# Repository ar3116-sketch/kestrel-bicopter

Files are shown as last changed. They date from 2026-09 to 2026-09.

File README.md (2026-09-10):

# Kestrel Mini R4

A matte-black, Black Hawk inspired **bicopter**, modeled in FreeCAD with electronics and wiring. Two lift motors and two independent tilt servos provide the control inputs. There is no tail rotor.

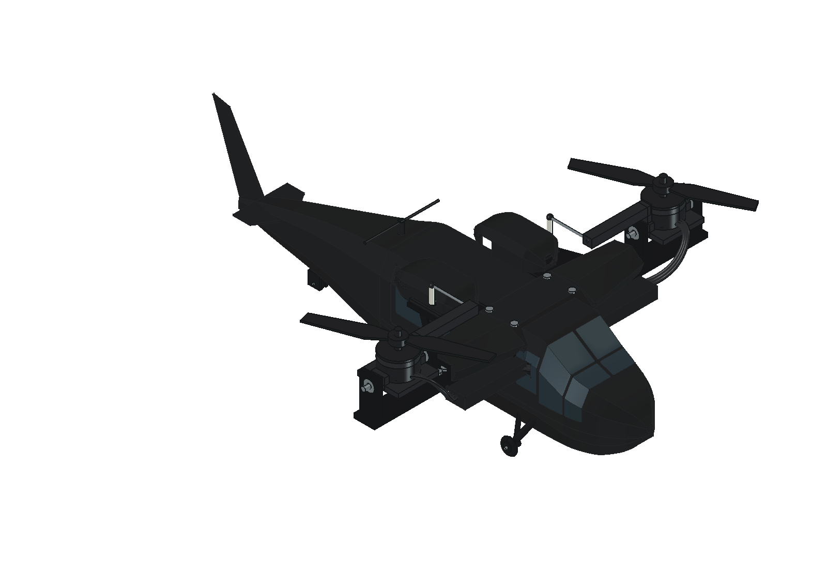
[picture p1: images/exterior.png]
Kestrel exterior


**Fit prototype, not flight-qualified.** Estimated mass is **665 g**, or **731 g with 10% growth**. Calculations support takeoff in principle. Actual thrust, servo tracking, printed strength, assembly retention and flight-controller integration still need physical verification.

## Start here

- [PDF build and engineering guide](output/pdf/Kestrel_Mini_R4_Build_Guide.pdf)
- [Parts list: buy, print and bench equipment](docs/PARTS_LIST.md)
- [FreeCAD assembly](cad/Kestrel_Mini_R4.FCStd) and [STEP](cad/Kestrel_Mini_R4.step)
- [40 installed STL pieces](stl/) and [2 optional guards](stl/optional_guards/)
- [Wiring overview](engineering/wiring_overview.svg) and [42-route wire schedule](engineering/WIRE_SCHEDULE.md)
- [Engineering review](engineering/ENGINEERING_REVIEW.md), [flight audit](engineering/INDEPENDENT_FLIGHT_AUDIT.md), and [tail assessment](engineering/TAIL_ASSESSMENT.md)
- [Assembly and qualification plan](docs/BUILD_AND_TEST.md)
- [Reproduction instructions](REPRODUCE.md)

Open the FCStd in FreeCAD. Run `OPEN_KESTREL.FCMacro` for shell visibility and independent tilt inspection. The +/-25 degree sliders show geometric articulation; they are not validated operating limits. The native file is a grouped installation model, with provisional purchased-part envelopes and a Python geometry generator, rather than a fully constrained assembly/feature history.

## What the calculations say

| Case | Estimated mass | Vertical thrust/weight at 12 V | At 16 V |
|---|---:|---:|---:|
| Baseline | 665 g | 1.82 | 2.29 |
| 10% mass growth | 731 g | 1.65 | 2.09 |

These use the published original EMAX RS2205 2300KV / HQ5045BN two-blade table with an **assumed 15% installation loss**. The assumption is not a measured guarantee. At the growth mass and low voltage, the design misses its preferred 1.8 vertical margin. Bank, tilt, simultaneous commands and gusts consume reserve. Fresh-pack 16.8 V is outside the available thrust table.

The tail prints weigh **30.9 g**, already counted in the baseline. The calculated CG lies 0.82 mm aft of the rotor pivot plane. The tail is not inherently incompatible with bicopter control, but crosswind and its added rotational inertia matter; see the dedicated assessment. No wind envelope is approved.

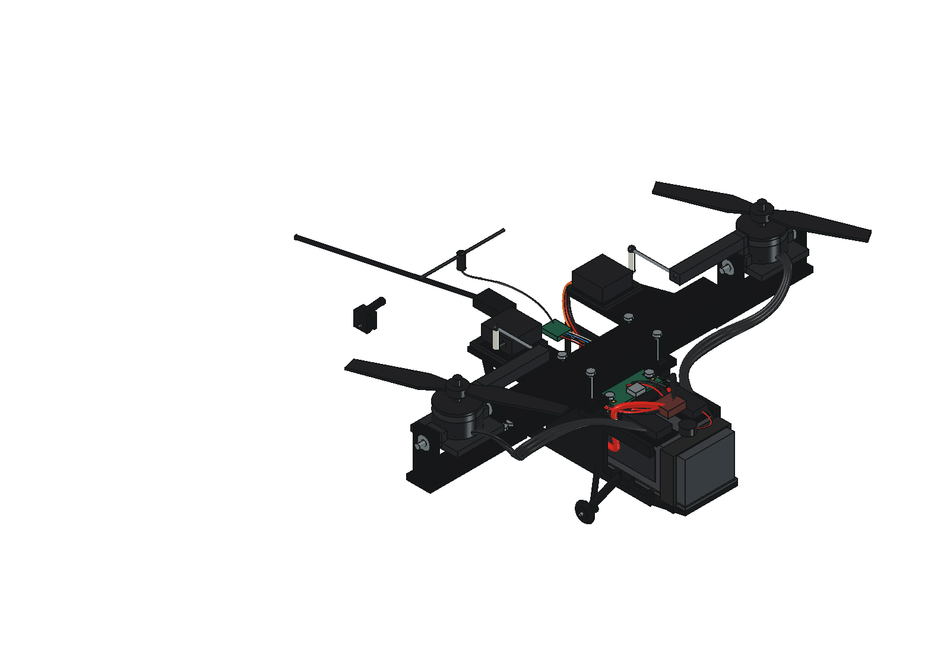
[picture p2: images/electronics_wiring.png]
Installed electronics and wiring


## Evidence and open work

The R4 checks report 167 valid physical shapes, 42 closed printable meshes, 22 sampled rotor poses and 42 neutral wire routes. Minimum prop-to-fixed clearance in the sampled poses is 9.906 mm. The wiring check uses finite mesh sampling, not continuous flexible-harness simulation. No physical tests, CFD, validated full-flight simulation or flight qualification have been completed.

Battery SKU, final hardware interfaces, tail splice and retention, motor/ESC/servo thermal performance and exact firmware configuration remain open. Do not treat a successful CAD or mathematical check as proof of an airworthy build.

The manufacturer material in `source/` is retained for engineering traceability; see [NOTICE](NOTICE.md). This project is an independent hobby design and is not affiliated with Sikorsky, Lockheed Martin or the hardware manufacturers.

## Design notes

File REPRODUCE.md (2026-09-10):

# Reproduce the prototype checks

The native FreeCAD file is a grouped installation model with named parts and wires. The generator creates Part/PartDesign features from dimensions; the DesignBasis spreadsheet documents parameters and does not drive a live constrained feature history. Purchased parts are installation envelopes; detailed received-hardware interfaces remain provisional.

From this folder, run `python3 scripts/analyze.py`, then `python3 scripts/independent_audit.py` for the mass, thrust, control and structural screens. These use the saved inventory and source tables. Run `python3 scripts/write_report.py` and `python3 scripts/wiring_diagram.py` to regenerate the reports and wiring overview.

Run `scripts/build_freecad.py` inside FreeCAD to rebuild geometry. It closes and recreates the document named Kestrel_Mini_R4, so preserve any manual edits under a different name first. Keep `scripts/profile_surfaces.py` beside it. The original Samson and previous Kestrel revisions are separate files. Shell skin uses a section-coordinate inset, not a guaranteed exact surface-normal thickness.

For isolated read-only geometry checks, use FreeCADCmd with `scripts/check_fixed_clearances.py` and `scripts/check_wire_samples.py`. The latter uses NumPy and records its finite sampling resolution, constructive passage exclusions, canonical source hash and native-file hash. It does not prove continuous motion clearance or flexible wire behavior. The fixed check examines selected component pairs and 22 rotor poses; its method is separate from the wire sampling check.

With the native document open in FreeCAD, `scripts/refresh_exports.py` refreshes inventory, closed-mesh/size checks, STL files, STEP and the saved document. Run the analytical and geometry checks again after any geometry or hardware change. Run the wire check after the final native-file save so its recorded hash matches the delivered file. `scripts/package_release.py` validates the evidence and packages selected artifacts; its name refers to an archive release, not flight qualification.

`OPEN_KESTREL.FCMacro` provides shell visibility and independent ±25° inspection sliders. It hides neutral phase-wire paths while tilted, and returns the pods to neutral when closed. The ±25° geometric display is not a validated flight limit.

## Repository documentation and PDF

After analytical changes, run `python3 scripts/tail_audit.py` and `python3 scripts/build_parts_list.py`. The first performs a limited tail mass/inertia and crosswind sensitivity screen; it does not validate an aerodynamic coefficient or wind envelope.

Install `requirements-docs.txt` into a Python environment and run `python3 scripts/build_pdf.py` to recreate `output/pdf/Kestrel_Mini_R4_Build_Guide.pdf`. The PDF builder needs ReportLab/Pillow; the independent flight audit also requires NumPy. FreeCAD and its OCCT modules are required separately for CAD operations. Render the PDF with Poppler and inspect all pages after any content change; PDF byte hashes vary with build timestamps.

Run `python3 scripts/package_release.py` after the saved CAD and reports agree. It checks existing geometry evidence, refreshes `MANIFEST_SHA256.json` and creates `outputs/Kestrel_Mini_R4_Repository.zip`, including the PDF, parts list and tail assessment. It does not repeat all underlying CAD computations. Historical `outputs/` and temporary PDF renderings are ignored by Git.

Run `python3 scripts/verify_repository.py` for a read-only manifest, native-file, parts/mass and local-link consistency check. Refresh the manifest after intentional modifications. Repository validation does not change `flight_release=false`.

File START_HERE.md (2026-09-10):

# Kestrel Mini R4

Black Hawk inspired bicopter in matte black, built in FreeCAD. Two propulsion motors, two tilt servos; optional guards are hidden in the baseline view.

Revised exterior

**665 g estimated / 731 g with 10% growth. Preliminary design; not flight released.**

Open [the FreeCAD assembly](cad/Kestrel_Mini_R4.FCStd) or run `OPEN_KESTREL.FCMacro` inside FreeCAD for the shell switch and tilt sliders. [STEP assembly](cad/Kestrel_Mini_R4.step) is also included.

Read [the independent flight audit](engineering/INDEPENDENT_FLIGHT_AUDIT.md), [the engineering review](engineering/ENGINEERING_REVIEW.md) and [wire schedule](engineering/WIRE_SCHEDULE.md) before printing or buying. `stl/` contains 40 installed fit-prototype parts sized for the Centauri Carbon. `stl/optional_guards/` contains the two optional guards, totaling 25.4 g. Exact hardware interfaces and physical acceptance tests remain open.

Electronics and wiring

Calculations predict enough lift near the nominal mass, with roughly 3–4 minutes of hover on a 4S1300 pack. The screenshot's four-cell 21700 pack would put this design around 799 g before contingency, so it is not the baseline.

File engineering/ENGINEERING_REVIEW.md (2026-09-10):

# Kestrel Mini R4 — engineering prototype

Designed in FreeCAD, 9 September 2026. Revision reflects the requested matte-black Black Hawk inspired silhouette: short rounded nose, sloping windshield, rectangular cabin windows, hollow roof fairings, low tail boom, swept fin and wheel gear. Original geometry inspired by the user's larger Samson model; no original CAD was overwritten. The two screenshot parts lists are references, not commands. No parts have been bought.

**Digital design and preliminary feasibility only. The aircraft has not been built, weighed, thrust-tested, structurally proof-tested, or flown. CAD cannot certify that it will fly.** This package is suitable for design review and fit prototypes; it is not a released flight kit.

## Main result

The calculated nominal build is **665 g**, including a **77 g installation allowance**. The budget with 10% growth is **731 g**, leaving **69 g** below the user's 800 g ceiling. Printed material is **251 g**, evaluated at full CAD solid volume and a conservative assumed 1.24 g/cm³. This is not a slicer prediction or measured print mass.

There are **167 modeled objects including two optional guards**, **40 installed printable pieces**, and **42 individually modeled wire routes**. Rotor center spacing is 234 mm and prop diameter is 127 mm, giving 361 mm overall rotor span without guards. The swept fin gives approximately 386 mm overall length. Optional guards have 142.2 mm OD and 376.2 mm overall span. Body dimensions are not a uniform scale of the old design. The old package recorded 2699.9 g before contingency; this design is about 75% lighter on its own mass basis.

At nominal mass, the reference calculation with an assumed installation factor gives vertical thrust/weight of 1.82 at 12 V and 2.29 at 16 V, with installed thrust assumed to be 85% of the manufacturer stand result. Expected static hover duration is roughly **3–4 minutes** using 80% of nominal pack energy. Airflow obstruction, battery aging, wind, maneuvering and actual material mass can worsen this.

**The model predicts enough static lift at nominal weight. Maneuvering and stable controlled flight are not yet established.** The independent audit in `INDEPENDENT_FLIGHT_AUDIT.md` corrects the earlier servo-gyro omission and shows the sensitivity to weight and installed thrust. The 85% factor is an assumption, not a measured conservative bound. Keep the initial build near the nominal mass. At the 800 g ceiling, low-voltage tilt reserve is substantially weaker. The baseline omits the guards. Fitting both adds 25.4 g, taking nominal mass to 690 g. No positive thrust gain is credited to them. Current screens below are analytical limits; hardware has not been configured to enforce them.

## What to open

- `cad/Kestrel_Mini_R4.FCStd`: native FreeCAD assembly, individual objects, mass properties, named nets and grouped electronics.
- `cad/Kestrel_Mini_R4.step`: neutral assembly, commercial components represented by simplified installation envelopes.
- `OPEN_KESTREL.FCMacro`: open the model with independent tilt sliders and a shell on/off switch. Wiring depicts neutral installation; flexing wires are hidden when articulating.
- `stl/`: installed fit-prototype parts, moved to positive print coordinates; optional guards are in their own subfolder. Propellers are deliberately excluded.
- `engineering/calculations.json`, `inventory.json`, `final_clearance_report.json`, `wiring_routes.json`: reproducible detailed evidence.
- `scripts/build_freecad.py`: dimension-driven generator; edit the geometry parameters in this source and rebuild inside FreeCAD. The DesignBasis spreadsheet is documentation, not live constraint linkage.

## Two motors and maneuvering

Yes: two independently controlled, counter-rotating propulsion motors plus two independent tilt servos provide the four primary control inputs. Collective thrust controls climb/descent, differential thrust controls roll, common fore/aft rotor tilt supplies pitch/forward-backward control, and differential fore/aft tilt supplies yaw. Sideways motion uses banking; this is not six independently actuated axes. A supported flight controller mixes and stabilizes these coupled motions. A tail rotor is not required in this arrangement. The tail fin is a body feature, not a substitute for active stabilization. Betaflight lists its BI airframe with two motors and two servos [7].

## Mass and balance

| Allocation | Grams |
|---|---:|
| Installed printed airframe, shell, cradles, gear and mounts | 250.9 |
| Purchased components already allocated in CAD | 337.0 |
| Harness and secondary connectors | 36 |
| Additional screws, nuts, spacers and retention hardware | 25 |
| Straps, foam, ties and insulation | 8 |
| Adhesive and light finish | 8 |
| Nominal | 664.9 |
| With 10% growth | 731.4 |

The purchased total includes two motors (60 g), two props (6 g), two ESCs (16 g provisional), two Blue Bird digital servos (24 g planning), FC (10 g), receiver including antenna (2.2 g), UBEC (21 g), battery with stock leads (170 g allowance), main XT60 (4 g), input capacitor (3 g), buzzer (2 g), four MR104 bearings (5.2 g assumed), metal trunnions (8 g assumed), two horns (1.6 g) and links (4 g). The supplementary hardware and harness allowances intentionally remain even where simplified zero-mass CAD markers exist. Some stock wire mass is also covered conservatively by the harness floor. Nothing is reclaimed as fictitious margin.

Coordinate convention: +X nose/forward, +Y left, +Z up. Origin is midway between rotor axes in plan at z=0; actual transverse pivots are at z=35 mm. Estimated all-up CG = **(-0.82, -0.03, 4.44) mm**. Nominal pitch moment arm from CG to pivot is **30.6 mm**. Sliding the battery is the balancing adjustment. Target actual CG within ±2 mm in X/Y of the pivot centerline; do not assume a low battery makes a bicopter passively stable. The estimated X error implies about 1.5° geometric trim, with final correction based on measured CG. The nominal calculation is inside the ±2 mm target; measure and trim the assembled aircraft. The layout places the battery center at x=39 mm and relocates the XT60, balance plug and capacitor aft of the pack. Main leads run in side channels; the cosmetic roof covers are hollow.

Bounding-box approximations to the principal inertias are 0.00231, 0.00222, 0.00371 kg·m². These are only model inputs; measure inertia or retune to the built aircraft. A ±50% control-effectiveness range was screened in the simplified simulation.

## Propulsion and energy calculation

Reference is **genuine EMAX RS2205 2300KV with HQ5045BN two-blade props**, with a matched CW/CCW pair. RS2205-S, generic RS2205 clones, different KV, and similarly named triblades are not equivalent evidence. The original EMAX table is retained in `source/motor_2.jpg`. It provides current and thrust at 12 V and 16 V. Piecewise interpolation stays inside those tables; no extrapolation is used.

Equations: required stand thrust per motor = mass/(2 × 0.85); P = 2VI + 5 W hotel load; usable energy = 14.8 × 1.3 × 0.8 = 15.39 Wh; duration = 60E/P. The 15% installation penalty and 5 W hotel load are assumptions. Static data gives no reliable throttle percentage, forward-flight speed, or climb performance.

| Mass g | Loaded V | Hover pack A | Hover W | Vertical T/W | T/W at 20° tilt | Idealized hover min |
|---:|---:|---:|---:|---:|---:|---:|
| 665 | 12 | 19.6 | 235 | 1.82 | 1.71 | 3.9 |
| 665 | 16 | 16.6 | 266 | 2.29 | 2.16 | 3.5 |
| 731 | 12 | 21.9 | 263 | 1.65 | 1.56 | 3.5 |
| 731 | 16 | 18.7 | 300 | 2.09 | 1.96 | 3.1 |
| 800 | 12 | 24.9 | 299 | 1.51 | 1.42 | 3.1 |
| 800 | 16 | 20.9 | 334 | 1.91 | 1.79 | 2.8 |
| 690 | 12 | 20.5 | 246 | 1.75 | 1.65 | 3.8 |
| 690 | 16 | 17.4 | 279 | 2.21 | 2.08 | 3.3 |

The 12 V maximum uses the table's last available 20.7 A point. The 16 V maximum is interpolated at a 24 A per-motor screen to leave nominal room below the 30 A ESC rating. At 16.8 V fresh-pack full throttle, current may exceed this screen; measure it before selecting output limits, prop or ESC. A throttle cap is not a closed-loop current limit. Cooling and transient margin must be verified. Do not claim the printed guards contain a failed propeller.

Ideal actuator-disk hover power is 66.8 W using sea-level density 1.225 kg/m³ and two 127 mm disks. The much larger electrical prediction reflects real small-prop, motor and installation losses. No CFD has been performed.

The screenshot’s 21700 option leaves inadequate mass reserve in this design: four cells at a 71 g maximum each plus 20 g pack integration make a 304 g 4S1P pack. Substitution alone gives **799 g before growth allowance**, and **879 g with 10% growth**. The larger pack also requires a different tray/body. A single cell is not a 4S pack. The user-linked listing distinguishes 40 A without thermal cutoff from the 90 A thermally constrained rating; neither is credited as a tested aircraft pack capability. No custom cell pack is modeled or recommended for the initial build.

## Mechanical and control checks

The motors tilt about transverse bearing-supported axes. Cradles and commercial motor/prop envelopes move together; optional guards follow the same pivots when fitted. Four 4×10×4 mm bearings and metal trunnions support the rotors; servos do not carry the rotor's main bending load. Two 14 mm horns with roughly 35 mm links give nominal 1:1 motion. Exact shoulder-bolt retention, washers, spline/horn fit and servo mounting ears remain received-hardware interfaces, not certified machined drawings.

At hover, define inputs [dTL,dTR,dL,dR] and outputs [vertical force, roll moment, pitch moment, yaw moment]. With d=0.117 m, h=0.0306 m and each hover thrust T, the allocation is:

```
Fz = dTL + dTR
Mx = d (dTL - dTR)
My = h T (dL + dR)
Mz = d T (dR - dL)
```

The allocation determinant is nonzero (-0.0177861), so the four local controlled quantities have independent authority. This does **not** establish full-flight stability: common tilt also creates horizontal force, gyroscopic/reaction torques couple axes, servos have delay and backlash, and the aircraft is underactuated in translation. Opposite motor rotation and correct mirrored servo signs must be proved with props removed. No 90° conversion or wing-borne flight is intended.

An attitude-only actuator-lag model was integrated for 18 pitch/yaw cases: initial 10° error, lag 40/80/150 ms, gain ratio 0.5/1.0/1.5, ±20° command limit, 2 rad/s tilt-rate bound, 2 ms steps. All 18 ended within 0.5° at 8 s. These are **synthetic numerical responses, not FreeCAD dynamics, hardware-in-loop tests, or flight-controller PID values**. Translation, aerodynamic damping, pure transport delay, vibration and sensor/firmware behavior are not included. `analyze.py` reproduces every trace. Do not copy the model gains to a flight controller.

For the 24×14 mm, 2 mm wall crossbeam: I=3821 mm⁴. With 10.1 N per side and 90 mm effective cantilever, nominal stress is 1.67 MPa and deflection 0.43 mm at an assumed E=1500 MPa. Applying a local factor 2 gives 3.33 MPa; against an **assumed** 5 MPa working limit the screening margin is 1.50. It is a beam calculation, not FEA. It does not qualify layer adhesion, bolt holes, creep, fatigue, wheel gear, optional bonded spokes, local buckling or impact resistance.

The selected Blue Bird servo’s published 6 V catalog torque is 5.5 kg·cm = 0.539 N·m. The chosen quarter-catalog working screen is 0.135 N·m; this is not a manufacturer continuous rating. The base thrust-offset, gravity, acceleration and harness load totals 0.0372 N·m. Adding a conservative radial-mass-bound gyroscopic case at 24,600 RPM and 45°/s body roll gives 0.0735 N·m and 1.83× margin against that chosen screen. The RPM, rotor inertia, harness drag and loaded tracking still require measurement. Neither the larger torque number nor a digital input rate establishes dynamic stability.

The ±10° pod / ±10° bank / ≤45°/s rate envelope is only a proposed qualification candidate. It is not implemented in firmware or established as safe flight limits. Simultaneous pitch and yaw share the pod angles: abs(common tilt)+abs(differential tilt) must remain within the absolute limit. The independent audit shows sensitivity and the much weaker reserve at higher rates.

The 52 mm printed crank extension (8×7 mm section) screens at 4.55 MPa and 0.78 mm for a 0.08 N·m actuation screen. This does not resolve spline/fastener stress. Body roll creates gyroscopic torque about each servo tilt axis. Prop and motor-bell inertia, RPM and roll rate must be included; opposite prop rotation does not remove each servo’s local load. See the added gyroscopic cases in calculations.json and the independent audit. The stronger servo does not strengthen this printed crank or establish its fatigue life.

## Digital clearance result and limitations

- Valid physical B-reps: 167 / 167.
- All printable bounding boxes fit within the 256 mm Centauri Carbon build envelope; every dimension is below 244 mm.
- All 42 exported print meshes are closed, including the two optional guards.
- Prop annulus positions checked: 22, in 5° increments from −25° to +25° on each side. Blade-height envelope is 5 mm, excluding the 15 mm hub/motor radius.
- Prop-to-fixed intersections: 0. Smallest nominal sampled prop-to-fixed clearance: 9.91 mm.
- Electronics/structure and principal component-pair intersections: 0.
- Moving guard/cradle versus fixed-object intersections: 0.
- Neutral wiring: 42 routes and 179,487 sampled points; no confirmed sampled overlaps in the final screen. Main leads versus nonterminal electronics and the splice versus shell also pass that approximate screen.
- All three wheels lie on z = −56 mm; wheel/fork BRep intersections are zero. Metal axles are intentional contacts.

Fixed-part BRep completion: **True**. Wire sampling completion: **True**. See `final_clearance_report.json`, `wire_sampling_check.json`, `mesh_checks.json`, and `landing_gear_check.json` for the separate methods and evidence.

The wire check reconstructs the canonical centerlines, confirms their lengths against saved CAD, samples every approximately 0.5 mm with 16 points on each of two radial rings plus center points, and classifies points against meshes requested at 0.05 mm linear deflection. It requires agreement between two ray directions. This is finite approximate sampling, not a continuous intersection proof. Matching service passages are cut using the same route with radius increased by 0.6 mm and recorded as constructive exclusions, not claimed independently Boolean-verified. A slow earlier wire/shell Boolean run was superseded by this bounded method.

The revised routes avoid the windshield, rise behind the ESCs through defined FC-deck passages, clear motor-cradle edges, pass through cabin pillars beside the enlarged windows, and enter the antenna mast along a straighter riser. The buzzer was moved above the battery to remove a component-envelope overlap. **These checks do not simulate moving-wire deformation, screw-tool access, manufacturing tolerance, prop flex, bearing play, heating, fatigue or impacts.** Maintain at least 3 mm measured loaded prop clearance after those effects; the CAD number is not that measurement. Optional guard radial gap is 6 mm at neutral.

## Electrical architecture

Power and signal overview

4S battery → XT60 → insulated star power splice → two ESCs, FC battery input, dedicated 6 V UBEC, and 470 µF/35 V low-ESR capacitor across the bus. All grounds share a reference. FC internal 5 V powers the receiver and buzzer; the separate 6 V positive only feeds servo positives. **Never connect the 6 V servo positive to FC 5 V, and never parallel the regulator positives.** ESC main current bypasses the FC's integrated current sensor in this layout, so that sensor does not measure total aircraft current. Battery alarms must be voltage based unless a correctly integrated external current sensor is added.

| Function | Connection | Requirement |
|---|---|---|
| Left ESC signal | FC S1 / PC9 | OneShot125 or supported PWM; calibrate exact ESC |
| Right ESC signal | FC S2 / PC8 | Same protocol as left; these share TIM8 |
| Left servo signal | FC S9 / PB14, servo resource 1 | Separate TIM12, initialize at 50 Hz |
| Right servo signal | FC S10 / PA6, servo resource 2 | Separate TIM13, initialize at 50 Hz |
| Receiver TX | FC RX2 / PA3 | CRSF, not the inverted SBUS pad |
| Receiver RX | FC TX2 / PA2 | CRSF telemetry |
| Receiver power | FC 5 V and GND | RP1 is a 5 V receiver |
| Servo power | Dedicated UBEC 6 V and GND | Verify with meter before connecting |
| Buzzer | FC BZ+ / BZ− | Active 5 V buzzer; verify polarity |
| Battery balance connector | Four cells / five taps | Only for compatible balance charging and checking |

Matek target pins were checked against the pinned manufacturer-config repository. Actual firmware must contain `USE_SERVOS` and `USE_UNCOMMON_MIXERS`; the BI mixer is conditional in current source. Confirm `mixer list` includes BI, actual output resources and signal waveforms. The ESC named here is older BLHeli hardware: do not assume DShot or bidirectional telemetry. Blue Bird specifies input rates up to 333 Hz; initialize at 50 Hz for output mapping and verify actual timing before raising it. Input frame rate is not loaded mechanical bandwidth.

UBEC manufacturer rating: 5 A continuous, 2–8S input, selectable 5/6/7.4 V. Use 6 V; no 15 A burst credit. Require measured combined servo current below 4 A in the worst intended maneuver, with no FC reset or servo-rail collapse. Servo stall current was not established from the exact digital-servo datasheet. Never deliberately hold a stalled servo as a continuous load. Verify transient performance with the real harness and temperature.

Phase extensions are modeled as 18 AWG silicone wire; retain only necessary OEM 20 AWG tails. ESC power branches are 18 AWG, main battery leads 14 AWG, servo branches 24 AWG, signals generally 26 AWG. Main wire resistance and I²R examples are in `calculations.json`. Copper resistance is evaluated at 20°C and must be increased for temperature. The JSON also screens 49 A in each main lead and 24 A in each branch as an upper electrical load case; those heating values are not approved continuous ampacities. Phase RMS current is not identical to measured battery current; those heating examples are screening assumptions, not ampacity ratings. Prefer short soldered, strain-relieved joints over heavy bullet connectors. Verify polarity, insulation, branch heating and motor direction on the bench.

## Provisional shopping specification

| Qty | Part | Design basis / status |
|---:|---|---|
| 2 | Genuine EMAX RS2205 2300KV | 27.9 mm diameter, 31.7 mm overall, 16×19 mm M3 pattern, 30 g each. Legacy availability; kit may supply four. |
| 1 pair | HQ5045BN two blade, CW + CCW | Exact thrust reference. Commercial balanced propellers; never use the visual CAD blades as print files. |
| 2 | EMAX Lightning 30A ESC | 4S-capable older OneShot/PWM design; 27×12×5 mm / 8 g reserved envelope is provisional. Verify stock and exact dimensions. |
| 2 | Blue Bird BMS-115WV+ digital metal gear | 23.2×10×23 mm body, 12 g planning each (catalog 11±0.5 g), use 6 V, 25T OEM matching horns. Shaft/ear locations are provisional until measured. |
| 1 | Matek F405-TE | 36×46 mm, 10 g, target MATEKF405TE_SD. Board mounting holes and exact component stack need confirmation. |
| 1 | RadioMaster RP1 V2 + antenna | 13×11×3 mm, 2.2 g. Pair with a compatible 2.4 GHz ELRS transmitter. |
| 1 | Hobbywing UBEC 5A | 50×17×10 mm, 21 g, set to 6 V. |
| 1 | Tattu-class 4S 1300 mAh LiPo | Select actual SKU ≤76×38×31 mm, ≤170 g; source's 72×36×29 mm soft pack is the dimensional reference. No C-rating proof assumed. |
| 4 | MR104 bearings, 4×10×4 mm | Purchased metal bearings; print only the housings. |
| 4 | 4 mm smooth shoulder trunnions + retention | Metal; exact stack, threads, shims and locking design require hardware fit. |
| 2 | 14 mm effective-radius OEM horns + M2 ball links | Correct spline; about 35 mm link center distance; no unsupported printed servo splines. |
| 1 | 470 µF / 35 V low-ESR input capacitor | Included Matek candidate, modeled separately; verify installed ripple/transients. |
| 1 | XT60 pair and 4S balance connector | Polarity and strain relief required. |
| 1 | Active 5 V buzzer | Connect to FC switched buzzer pins. |
| set | M3/M2 screws, nuts, spacers, straps, silicone wire | Full allowance retained; detailed receipt-based fastener release remains open. |
| ground | ELRS transmitter, 4S balance charger, wattmeter/thrust stand | Not airborne mass. FlySky transmitter in the screenshot does not bind to RP1 ELRS. |

No purchases were made. Links below are evidence and sourcing starting points, not a confirmed all-in-stock procurement release. The exact legacy motor/prop pair is essential to the calculations; substitute modern parts only with a new matched thrust table and interface update.

## Centauri Carbon print and assembly plan

The cosmetic fuselage and glazing use 1.0 mm nominal walls; roof pods use approximately 1.1 mm walls. These skins are not credited as the primary load-bearing frame.

The model maximizes printed airframe content: keel, crossbeam, bearing yokes, motor cradles, guards/spokes, trays, covers, antenna mast, tail, wheel struts and wheels. Bearings, trunnions, fasteners, motors, OEM servo horns, wiring, batteries and high-speed propellers remain purchased functional parts.

For fit coupons use ordinary PETG. For flight-critical hot motor cradles and highly loaded yokes, qualify a tougher heat-resistant filament such as suitable PA-CF with its manufacturer drying and print process on this printer. The mass analysis retains 1.24 g/cm³ for every printed solid; material strength is **not** inferred from the Centauri Carbon name or a generic carbon-filled filament label. Avoid PLA for hot loaded motor interfaces. Final material/process selection is open.

Start with 0.4 mm nozzle, 0.20 mm layers, 4–6 perimeters for structural parts; use more local shells at bolts rather than arbitrary overall infill. Thin shells are designed as material solids, not solid-filled fuselage volumes. Print the crossbeam flat with its long span in the XY plane, yokes with bearing axes vertical where practical, and motor cradles with continuous load paths across layers. Supports and reorientation are needed on several parts. Export coordinates only place each part above z=0; **they are not fully optimized print orientations or a ready-to-run slicer project**.

Calibrate 4 mm shaft and 10 mm bearing bores using small clearance coupons first. Never force a bearing into a cracked printed wall or clamp across both bearing races. Deburr wire apertures, add local insulation/strain relief, and keep antenna active elements away from conductive composite materials. Printed guards need bonded/fastened spoke attachment proof. Their present interface is suitable for a fit prototype; it is not a verified production joint.

Assembly sequence: weigh prints → fit shafts/bearings and verify free motion → dry-fit motors and horns with no props → assemble keel/crossbeam/wheel gear → mount battery and FC on isolators → install ESCs/UBEC/receiver → route and secure wiring → fit removable shells → measure CG → calibrate/motion-test with no props → only then perform a restrained propulsion and vibration test. Balance the actual final assembly before flight. Perform canopy retention, linkage backlash and fastener-locking verification on received hardware.

| Printable object | Full-solid mass g | Bounding box mm | Solids |
|---|---:|---|---:|
| P01_Battery_keel | 35.3 | 136.0 × 58.0 × 48.0 | 1 |
| P02_Crossbeam | 45.2 | 73.0 × 168.0 × 19.0 | 1 |
| P03_Avionics_deck | 6.3 | 54.0 × 49.0 × 4.0 | 1 |
| P09_Cabin_side_glazing_0 | 0.5 | 18.0 × 4.5 × 27.0 | 1 |
| P09_Cabin_side_glazing_0_segment_2 | 1.1 | 28.0 × 4.8 × 28.0 | 1 |
| P09_Cabin_side_glazing_0_segment_3 | 1.0 | 28.0 × 5.3 × 28.0 | 1 |
| P09_Cabin_side_glazing_1 | 0.5 | 18.0 × 4.5 × 27.0 | 1 |
| P09_Cabin_side_glazing_1_segment_2 | 1.1 | 28.0 × 4.8 × 28.0 | 1 |
| P09_Cabin_side_glazing_1_segment_3 | 1.0 | 28.0 × 5.3 × 28.0 | 1 |
| P06_Cabin_upper | 25.7 | 210.0 × 62.0 × 51.0 | 1 |
| P07_Cabin_lower | 23.0 | 208.8 × 62.0 × 17.0 | 1 |
| P08_Windshield | 1.4 | 20.0 × 29.9 × 40.0 | 1 |
| P08_Windshield_segment_2 | 0.7 | 12.5 × 28.8 × 26.3 | 1 |
| P08_Windshield_segment_3 | 1.4 | 20.0 × 29.9 × 40.0 | 1 |
| P08_Windshield_segment_4 | 0.7 | 12.5 × 28.8 × 26.3 | 1 |
| P19_Tapered_tail_boom | 22.8 | 150.0 × 56.6 × 64.5 | 1 |
| P04_Tail_spine | 3.1 | 163.3 × 12.0 × 35.5 | 1 |
| P05_Vertical_tail_fin | 2.2 | 52.0 × 1.3 × 70.0 | 1 |
| P05_Horizontal_tailplane | 1.6 | 31.0 × 48.0 × 1.2 | 1 |
| P17_Shoulder_cowl__1 | 4.3 | 46.0 × 52.0 × 20.0 | 1 |
| P20_Servo_engine_cowl__1 | 4.3 | 63.0 × 30.4 × 21.0 | 1 |
| P22_Cable_raceway__1 | 4.0 | 17.0 × 54.0 × 10.0 | 1 |
| P10_Main_gear__1 | 1.3 | 27.7 × 17.5 × 26.7 | 1 |
| P23_Main_wheel__1 | 0.6 | 14.0 × 4.0 × 14.0 | 1 |
| P17_Shoulder_cowl_1 | 4.3 | 46.0 × 52.0 × 20.0 | 1 |
| P20_Servo_engine_cowl_1 | 4.3 | 63.0 × 30.4 × 21.0 | 1 |
| P22_Cable_raceway_1 | 4.0 | 17.0 × 54.0 × 10.0 | 1 |
| P10_Main_gear_1 | 1.3 | 27.7 × 17.5 × 26.7 | 1 |
| P23_Main_wheel_1 | 0.6 | 14.0 × 4.0 × 14.0 | 1 |
| P24_Tailwheel_fork | 0.8 | 19.6 × 7.0 × 25.5 | 1 |
| P25_Tailwheel | 0.3 | 11.0 × 3.0 × 11.0 | 1 |
| P11_L_bearing_yoke | 10.6 | 18.0 × 74.0 × 35.0 | 1 |
| P12_L_motor_cradle | 10.4 | 36.0 × 85.0 × 22.5 | 1 |
| P14_L_servo_retainer | 0.6 | 29.0 × 30.0 × 2.5 | 1 |
| P15_L_ESC_tray | 1.2 | 31.0 × 16.0 × 2.0 | 1 |
| P11_R_bearing_yoke | 10.6 | 18.0 × 74.0 × 35.0 | 1 |
| P12_R_motor_cradle | 10.4 | 36.0 × 85.0 × 22.5 | 1 |
| P14_R_servo_retainer | 0.6 | 29.0 × 30.0 × 2.5 | 1 |
| P15_R_ESC_tray | 1.2 | 31.0 × 16.0 × 2.0 | 1 |
| P16_Antenna_mast | 0.1 | 5.0 × 5.0 × 10.0 | 1 |

## Required physical results before free flight

1. Weighed installed mass ≤800 g and preferably close to the nominal calculation; the 800 g ceiling alone does not meet the preferred thrust-reserve gates; CG within ±2 mm X/Y and below the tilt axes. Re-run calculations with measured masses.
2. Fit every received component, nut, shoulder shaft and OEM horn; prove guard/spoke, keel, servo and shell retention. Verify no part depends on friction alone for flight retention.
3. With props removed, verify FC orientation, motor assignment, mirrored servo signs, failsafe and arm/disarm. Confirm loss of radio commands motor shutdown. Capture and retain exact firmware version/configuration. Do not load arbitrary quad PID defaults for flight.
4. Measure thrust/current with the actual prop and chosen guard configuration at full and near-landing loaded voltage. Require at least **1.8× measured weight in vertical total thrust** as a preferred initial-flight gate, and ≥1.6× vertical capacity at maximum intended tilt. This may require reducing weight, limiting tilt, selecting a different prop/motor, or an ESC upgrade.
5. Inspect warm motor/ESC/BEC/wire temperatures, supply sag and servo tracking. Verify ≤24 A per ESC in the selected continuous operating region and adequate surge margin; this is a design gate, not a preconfigured limiter.
6. Loaded articulation through the configured range, realistic harness bending and gentle deflection: ≥3 mm prop clearance, no binding, no conductor rubbing, no bracket cracks. The independent audit proposes ±10° and ≤45°/s body rates only as conservative qualification candidates, not validated safe limits. Retain ±25° only as a checked geometric envelope, and fit positive travel stops before flight.
7. Proof one arm/yoke assembly to 20 N upward static load, inspect creep/deflection and joints; use a fixture, not a hand-held running rotor. Proof landing gear with a representative mass and inspect layer/joint damage. These tests do not establish unlimited fatigue life.
8. Establish low-gain restrained attitude response, check vibration logs and servo backlash, then short low-altitude trials in a suitable clear area. A tether changes dynamics; successful restrained testing is not itself stable free flight.

Open engineering items include exact purchased interfaces/retention details, actual filament allowables and fatigue, motor/ESC/servo temperatures, detailed power transients, flexible-harness fatigue, continuous motion clearance, complete six-degree-of-freedom stability, loaded servo bandwidth, real firmware integration and flight testing. No FEA, wind-tunnel test, hardware-in-loop run, or physical test was represented as performed.

## Source evidence

Sources accessed 9 September 2026. Product specifications are distinguished from modeling assumptions above; prices and stock can change. Source imagery is kept only as dimensional/performance reference.

1. [Original motor and manufacturer dimensions](https://emaxmodel.com/products/emax-rs2205-racespec-motor-cooling-series)
2. [Exact 2300KV / HQ5045BN thrust table](https://cdn.shopify.com/s/files/1/0469/7358/3518/t/3/assets/RS2205-2.jpg?v=1598532544)
3. [Motor / ESC kit](https://shop.emaxmodel.com/products/emax-rs2205-2300kv-2600kv-racespec-brushless-motor-with-3-4s-30a-blheli-lightning-esc-power-combo)
4. [Selected Blue Bird BMS-115WV+ dimensions and torque](https://www.blue-bird-model.com/products_detail/55.htm)
5. [Selected servo manufacturer](https://www.blue-bird-model.com/products_detail/55.htm)
6. [Matek F405-TE hardware, output timers, supply](https://www.mateksys.com/?portfolio=f405-te)
7. [Betaflight BI mixer](https://betaflight.com/docs/wiki/guides/current/Mixer)
8. [Betaflight target pin assignment](https://github.com/betaflight/config/blob/d78c5a23515c8e05534a2989a2415f3fcd76fd19/configs/MTKS/MATEKF405TE_SD/config.h)
9. [Betaflight servo mixer implementation](https://github.com/betaflight/betaflight/blob/9bf37771e1dad564d97245db479ddd7e3191c36a/src/main/flight/servos.c)
10. [Hobbywing 5A UBEC specifications](https://www.hobbywing.com/en/products/ubec-5a93.html)
11. [RadioMaster RP1 V2 receiver](https://www.radiomasterrc.com/products/rp1-expresslrs-2-4ghz-nano-receiver)
12. [Tattu 4S1300 dimensional reference](https://www.genstattu.com/blog/tattu-fpv-battery-recommend)
13. [Tenpower manufacturer cell list](https://www.tenpowercell.com.cn/products/cells)
14. [User-linked Tenpower cell / conditional current ratings](https://www.18650batterystore.com/products/tenpower-50xg-21700-5000mah-90a-battery)
15. [Centauri Carbon build envelope](https://www.elegoo.com/pages/elegoo-centauri-carbon)

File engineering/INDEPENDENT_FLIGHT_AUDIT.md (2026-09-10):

# Independent flight-feasibility audit — Kestrel_Mini_R4

Audit date: 9 September 2026. Inputs are the saved Kestrel_Mini_R4 inventory, mass calculation, moving-object list, EMAX thrust image and engineering review. This audit does not alter the CAD. The companion `independent_audit.py` and `independent_audit_calculations.json` reproduce the additional screens. The audited revision is **Kestrel_Mini_R4**; rerun after any inventory or propulsion changes.

## Finding

**The two-motor/two-servo arrangement can produce lift and all primary attitude-control moments in theory. At the saved nominal mass of 664.9 g, the matched EMAX motor/prop data supports a plausible takeoff and gentle-maneuver prototype. It does not establish that this aircraft will maneuver reliably.** The source arithmetic is correct, but the installation factor, actual battery/ESC performance and dynamic servo loads are not established. R3 omitted a body-roll gyroscopic servo load. R4 addresses that omission with a stronger provisional servo and explicit gyro/crank load screens; the improved calculated reserve is still conditional on actual rotating mass, RPM, servo tracking and structural proof.

The 10% growth build is 731.4 g. It remains below 800 g, but the weight limit is not a flight-performance guarantee. The report's own preferred 1.8 vertical / 1.6 at 20° thrust gates are not both retained at this mass at 12 V. These are chosen engineering targets, not universal physical thresholds; ideal takeoff needs more than 1.0 plus sufficient control reserve.

## Lift arithmetic independently reproduced

The original [EMAX matched thrust table](https://cdn.shopify.com/s/files/1/0469/7358/3518/t/3/assets/RS2205-2.jpg?v=1598532544) visually matches every current/thrust point transcribed in the saved script. At 12 V the table ends at 712 gf per motor and 20.7 A; at 16 V, interpolation at 24 A gives 897.33 gf. Applying the **assumed**, not measured, 0.85 installation factor gives total 1,210.4 / 1,525.5 gf. No extrapolation beyond source tables was used.

| Mass g | Loaded V | Vertical T/W | Vertical component at 20° pod tilt | At 20° pod tilt + 20° bank | Hover pack A, 5 W hotel assumption |
|---:|---:|---:|---:|---:|---:|
| 665 | 12 | 1.82 | 1.71 | 1.61 | 19.6 |
| 665 | 16 | 2.29 | 2.16 | 2.03 | 16.6 |
| 731 | 12 | 1.65 | 1.56 | 1.46 | 21.9 |
| 731 | 16 | 2.09 | 1.96 | 1.84 | 18.7 |
| 800 | 12 | 1.51 | 1.42 | 1.34 | 24.9 |
| 800 | 16 | 1.91 | 1.79 | 1.68 | 20.9 |

The bank column is an illustrative force-projection calculation, using cos(20°)² for orthogonal bank and fore/aft tilt. It excludes translation dynamics and control allocation saturation. It is not a demonstrated maneuver. If another 10% per-motor differential-thrust headroom is reserved, divide that column by 1.1. Do not interpret (T/W−1)g as a tested climb acceleration.

At 12 V and factor 0.85, the greatest mass meeting 1.8 vertical T/W is **672.4 g**; nominal mass would need to be **611.3 g** to retain that target after 10% growth. The corresponding 1.6 target at 20° permits **710.9 g**. These give explicit weight targets if these margins are required, rather than treating every sub-800 g build as equivalent.

Installation sensitivity at the 731.4 g growth mass, 12 V:

| Assumed installed fraction of stand thrust | Vertical T/W | At 20° |
|---:|---:|---:|
| 0.85 | 1.65 | 1.56 |
| 0.75 | 1.46 | 1.37 |
| 0.65 | 1.27 | 1.19 |

The 0.75 and 0.65 fractions are stress cases, not measurements or claimed worst-case bounds. A 15% loss allowance cannot be declared guaranteed conservative without testing actual body obstruction, prop, voltage and motor temperature. The optional guards need their own thrust measurement; absence of contact does not establish aerodynamic efficiency.

12 V is 3.0 V/cell for 4S and is used only as an adverse loaded-voltage screen. This audit does not recommend flying the battery down to that voltage. Actual landing thresholds require the chosen pack and measured sag. A fresh 4S pack is 16.8 V, outside the 16 V current table; full-throttle current at 16.8 V is unqualified. The 24 A number is a calculation cap and has not been enforced by hardware or firmware.

## Control, balance and simultaneous maneuvers

With +X toward the nose, +Y left and +Z up, let positive pod angle point thrust toward +X. Relative to the CG, the pivots have forward offset a = −CGx = 0.820 mm, half-spacing d = 117 mm and height h = 30.560 mm. Ignoring prop reaction and gyroscopic torque, the exact body-axis force/moment terms are:

```
Fz = TL cos(deltaL) + TR cos(deltaR)
Fx = TL sin(deltaL) + TR sin(deltaR)
Mx = d [TL cos(deltaL) - TR cos(deltaR)]       [small CGy correction omitted]
My = h Fx - a Fz
Mz = d [TR sin(deltaR) - TL sin(deltaL)]
```

This confirms independent collective, roll, pitch and yaw authority near hover. An additional ideal 12-state small-disturbance model including position, velocity, attitude and angular rates has controllability rank **12/12** when balanced. Thus the architecture is not inherently missing a control axis. This mathematical result assumes usable actuators and a correctly implemented controller. It is not a stability test of Betaflight, real servo delay, or the manufactured vehicle.

**Trim convention correction:** under the explicitly defined positive-forward-thrust convention, moment-free equal pod tilt is atan(a/h) = **+1.54°**. The original R3 `hover_trim_angle_deg` used atan(CGx/h), the opposite sign; R4 uses atan(−CGx/h) and records the convention. A numerical sign is meaningless without its physical convention. To remain stationary the body attitude must compensate the tilted thrust vector. Keeping the body level with this pod trim alone produces horizontal force. Balance the battery toward measured CGx = 0 rather than treating a low battery as passive stabilization.

With ±20° absolute pod travel, trim alone leaves approximately **18.46°** symmetric common/differential command reserve in the tighter direction. If common tilt is dc and differential tilt is dd, **|dc| + |dd| ≤ 20°**. Maximum pitch and maximum yaw cannot both be requested independently. The 20° thrust table does not demonstrate simultaneous pitch, yaw, roll and climb at their individual maxima.

At the nominal level force Fz=W, the ideal ±20° common-tilt pitch moments span -0.078 to 0.067 N·m. Ideal zero-common-tilt differential yaw at 20° is about 0.278 N·m. Those magnitudes indicate nonzero useful control authority. The inertia estimates are bounding-box approximations, so the associated angular accelerations in the JSON are screening values only.

The modeled moving pod centroids shift X CG by roughly 0.351 mm at common 20° tilt (excluding moving-link and wire mass). That is small, but is another reason not to treat the neutral CG and moment arms as exact constants throughout motion.

The 10% mass-growth allowance is a total-weight allowance, not a guarantee of balance. As a sensitivity example, 10 g added 200 mm aft of the pivot would move the present X CG aft by approximately 2.95 mm. Moving a 170 g battery forward by roughly 12 mm would compensate that added moment, if the received hardware and tray allow the travel. The assembled CG must be measured after cosmetic finishing and hardware substitutions.

The previous 18 attitude-only simulations deliberately choose stable feedback gains for a simplified model. They check numerical responses within that model; they do not validate actual firmware, longitudinal translation, sensor vibration, transport delay, coupled saturation, gust rejection or a six-degree-of-freedom flight envelope. Their successful convergence must not be presented as proof that the airframe has been flight-simulated and passed.

## Servo gyroscopic torque during roll: R3 gap and R4 correction

The earlier [EMAX digital servo drawing](https://cdn.shopify.com/s/files/1/0469/7358/3518/t/3/assets/EMX-SV-0276-DES-1.jpg?v=1598527275) gives 2 kgf·cm stall torque at 6 V (0.1961 N·m). Its 0.10 s/60° speed is **no-load** speed. Neither is a published continuous loaded rating. The old R3 quarter-stall working screen was 0.0490 N·m against 0.0372 N·m assumed load, leaving only 0.0118 N·m.

The audited revision provisionally selects **Blue Bird BMS-115WV+**. Its quarter-catalogue screen is 0.1348 N·m. The following prop-only estimate table uses that selected screen, not the superseded EMAX screen.

Gyroscopic torque is Omega × H, with H = Jrotor omega. During pod tilt about Y the gyro reaction is chiefly about X and loads the bearings/frame. **During aircraft roll about X, the gyro torque is about Y, the free pod hinge axis; holding pod angle therefore requires servo/linkage torque.** Opposite rotor spin can cancel a net airframe effect, but it does not eliminate each servo's load. This follows from [angular-momentum dynamics](https://ocw.mit.edu/courses/16-07-dynamics-fall-2009/resources/mit16_07f09_lec30/).

Using the modeled 3 g prop mass and 63.5 mm radius as a uniform radial-blade estimate gives Jprop = mR²/3 = 4.032e-06 kg·m². This mass distribution is assumed. Motor-bell inertia is additional and unknown; the simple radial mass bound mR² is three times the prop estimate. The added servo load may add to or subtract from existing loads with direction; the table conservatively adds magnitudes.

| RPM | Roll rate °/s | Prop-only gyro estimate N·m | Prior load + prop gyro N·m | Selected quarter-catalogue screen / sum |
|---:|---:|---:|---:|---:|
| 16000 | 45 | 0.0053 | 0.0425 | 3.17 |
| 16000 | 90 | 0.0106 | 0.0478 | 2.82 |
| 16000 | 180 | 0.0212 | 0.0584 | 2.31 |
| 20080 | 45 | 0.0067 | 0.0439 | 3.07 |
| 20080 | 90 | 0.0133 | 0.0505 | 2.67 |
| 20080 | 180 | 0.0266 | 0.0638 | 2.11 |

The original R3 1.32 servo margin was therefore **not a demonstrated maneuvering margin**. A 90°/s roll could nearly exhaust the EMAX screen using the prop alone; 180°/s exceeded it. Exact prop/bell inertia, thrust-axis eccentricity, loaded tracking, linkage friction and temperature must be measured or conservatively bounded. No aggressive roll-rate limit is approved by this calculation.

R4 also applies the deliberately larger bound J = (0.003×0.0635²) + (0.030×0.01395²) = 1.7935×10⁻⁵ kg·m²: all prop mass at its tip radius and all motor mass at the bell outer radius. This overbounds the motor bell only if received prop/motor masses and radii do not exceed those modeled. RPM is bounded to the source table's 24,600 RPM for this screen; actual fresh-pack RPM is not established.

| Roll °/s | Bounded gyro N·m | Prior load + bounded gyro N·m | Quarter-catalogue screen / sum |
|---:|---:|---:|---:|
| 45 | 0.0363 | 0.0735 | 1.83 |
| 90 | 0.0726 | 0.1098 | 1.23 |
| 180 | 0.1451 | 0.1823 | 0.74 |

The retained 8×7 mm, 52 mm crank is now screened at 0.08 N·m, rounded above the 45°/s bounded total. Nominal bending stress is 4.55 MPa and tip deflection 0.78 mm. A stronger servo does not strengthen this crank. Stress concentrations, material orientation, joint stiffness and fatigue are still open; proof-load and tracking checks are required.

## Power, structure and practical open items

- The 4S 1,300 mAh / 170 g battery is an envelope, not a selected verified SKU. At the growth mass, nominal-factor hover is ~19–22 A pack current; the maximum calculation is about 42–49 A with a 5 W hotel assumption. Two servos plus avionics may draw more than 5 W during maneuvers. Verify loaded voltage, pack temperature, capacity and actual current; a printed C rating alone does not prove this.
- The 49 A main-lead example dissipates roughly 6.3 W in the modeled 14 AWG positive/negative copper pair at 20°C; resistance rises with temperature. Six 18 AWG phase wires add heating whose current is phase RMS, not simply measured battery current. These resistance calculations do not prove thermal ampacity inside a closed black shell.
- The 5 A BEC supply rating is separate from actual servo transient current. Exact digital-servo stall current and transient rail behavior remain unknown. The existing separate 6 V servo supply/common-ground architecture is appropriate in principle; power integrity still needs measurement.
- The 3–4 minute energy estimate assumes 80% nominal pack energy and constant static power. It is an approximate hover-energy calculation, not a guaranteed usable flight duration. It excludes wind, maneuver duty cycle, actual voltage/efficiency evolution and battery aging.
- The beam calculation and nominal static loads are arithmetically consistent, but assumed filament E/allowable, layer orientation, creep, fastener joints, torsional gyro loads, fatigue, wheel gear and impact are not qualified. CAD shape validity and sampled clearance checks do not establish those properties.
- [Betaflight's documented BI layout](https://betaflight.com/docs/wiki/guides/current/Mixer) uses two motors and two servos. Actual firmware must contain the mixer, have correct pin resources and signs, and demonstrate loaded control behavior. Counter-rotating props and correct motor/servo directions remain essential.

## Candidate restricted test envelope and release gates

These numbers define a **bench-qualification target and later initial-flight candidate**, not an approved safe operating envelope. With the selected Blue Bird BMS-115WV+ there is currently no substantiated free-flight maneuver envelope. A reduced rate helps the calculated load, but cannot be certified until rotor inertia and loaded servo behavior are known.

1. Use the exact matched motor/prop pair, selected pack and final body. Weigh the complete aircraft with battery. Prefer a measured mass no greater than 672 g if relying on the 12 V / 0.85 reference and the 1.8 thrust target; a heavier build requires its own measured thrust result. Guards require a separate installed test.
2. At the intended lowest loaded operating voltage, demonstrate at least 1.8× measured all-up weight in total vertical thrust, and at least 1.6× weight in the worst planned projected-thrust condition. Do not use 12 V as the automatic battery landing setting. Derive actual alarms from selected-pack sag tests and manufacturer limits. Also test fresh-pack current at 16.8 V; measured temperatures/current must satisfy actual component continuous limits with margin.
3. Begin actuator qualification with ±10° pod travel, at most 10° bank and roll/pitch/yaw rate requests no greater than 45°/s. This deliberately small candidate range still requires the load checks below. Combined common/differential tilt must satisfy the absolute pod limit; retain independent physical stops and at least 3 mm measured loaded prop clearance.
4. Measure or bound prop plus rotating-bell inertia. Apply torque about the pod hinge representing measured thrust eccentricity, gravity, wire drag, tilt acceleration and **Jrotor·omega·45°/s** roll gyro load. At worst rotor RPM and warm operating conditions, demonstrate repetitive ±10° tracking without binding, loss of position, rail sag, thermal runaway or damage. Record step/oscillation phase delay and backlash. A fixture should reproduce loads; a hand near a running prop is not a load-test method. If continuous loaded tracking is insufficient, change servo/linkage and repeat mass/clearance/power checks rather than claiming the old stall torque is enough.
5. Verify both servos operating simultaneously keep their rail and the FC supply within actual specifications; check startup/transients, radio failsafe, mixer signs and motor order with props removed. Preserve firmware and resource configuration. Only after loaded actuator, propulsion, structural retention and vibration checks pass should the restrained response be used to set initial feedback gains and authorize short gentle free-flight trials. A tether changes dynamics and does not itself demonstrate free-flight stability.

The small-angle projection at 10° pod tilt plus 10° bank retains cos(10°)² = 0.970 of available thrust. This quantifies the proposed force benefit; it does not resolve gyro load, servo delay, gusts or coupled control saturation. Expand rate/angle/climb requests only from measured response and repeat the relevant projections/load checks.

## Selected R4 servo envelope and remaining interface work

The manufacturer's [Blue Bird BMS-115WV+](https://www.blue-bird-model.com/products_detail/55.htm) lists **23.2×10×23 mm**, **11±0.5 g**, catalogue torque **5.5 kgf·cm at 6 V**, speed **0.13 s/60° at 6 V**, dual ball bearings and a 25-tooth horn spline. It supports signals up to 333 Hz. R4 selects this installation envelope with **12 g per servo planning mass** and an initial 50 Hz signal configuration. Mounting ears, shaft location, spline, horn radius and cable exit still require a received-part interface check; it is not asserted to be a drop-in replacement or an exact vendor solid.

At one quarter of that catalogue torque, the same **unvalidated** screen is 0.135 N·m, compared with the earlier EMAX screen of 0.049 N·m. This offers substantially more numerical room for gyroscopic torque. The catalogue figure is not established here as continuous torque and published stall current was not found on that page. Thermal/current/tracking qualification still applies. Selection alone does not establish loaded bandwidth or justify higher-rate servo configuration.

## Defensible design status

**Lift feasibility: supported conditionally by matched reference data. Local control architecture: theoretically controllable. Under-800 g mass: projected, not weighed. Stable maneuvering, power/thermal limits and structural service life: unproven.** The key engineering issues are weak low-voltage reserve after growth, trim and combined-command limits, and body-roll gyroscopic servo/crank loading. R4 explicitly calculates these and adopts a stronger provisional servo. None of those changes makes the whole aircraft flight-verified.

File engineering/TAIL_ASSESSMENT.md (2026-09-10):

# Tail assessment - Kestrel Mini R4

The tail does not inherently prevent a bicopter from flying. It is included in the existing mass and balance calculation, but its aerodynamic effect is not yet qualified. This aircraft uses two independently tilting propulsion pods for control; the decorative helicopter tail needs no tail rotor.

## Mass and balance

The boom, spine, fin, horizontal tailplane and tailwheel prints total **30.86 g**. This is already included in the **664.9 g** nominal aircraft, not an additional charge. Tail hardware mass is in the shared fastener allowance; adhesive/finish are also shared, so this is not a separately weighed complete tail. The calculated CG is x = **-0.82 mm**, close to the rotor pivot plane x = 0. Tail component CG is x = -167.3 mm. Removing these parts without moving anything else would put CG at x = **7.28 mm**; that is a sensitivity calculation, not a recommended modification.

| Tail component | Allocated g | CG x, mm |
|---|---:|---:|
| P19 Tapered tail boom | 22.768 | -159.92 |
| P04 Tail spine | 3.147 | -121.45 |
| P05 Vertical tail fin | 2.187 | -256.45 |
| P05 Horizontal tailplane | 1.643 | -227.04 |
| P24 Tailwheel fork | 0.822 | -185.20 |
| P25 Tailwheel | 0.290 | -188.00 |
| Tailwheel M2 axle | 0.000 | -188.00 |

The same bounding-box inertia approximation used in the main audit assigns these tail parts 0.000957 kg m^2 in pitch and 0.000944 kg m^2 in yaw, approximately 43% and 25% of the respective totals. The long lever arm matters more than the modest mass alone. These are coarse geometry-based estimates, not measured inertia.

## Crosswind sensitivity, not an operating wind limit

The generator's own cubic tail-boom silhouette is integrated at 0.05 mm spacing from x=-255 to -105 mm. Boom side area is 57.81 cm^2; fin side area is 13.57 cm^2. Their sum is 71.38 cm^2, with area-weighted lever arm 179.0 mm aft of CG. The overlap is double-counted, shielding is omitted, and the rest of the aircraft is excluded. This is not a whole-aircraft force bound.

Use q = 0.5 rho V^2 and yaw moment N = q C integral[(CGx-x) dA], with rho=1.225 kg/m^3. Coefficients C=1.0 and 1.5 are arbitrary sensitivity inputs; neither is a measured value or guaranteed upper bound. Wind is uniform sideways relative flow, not forward speed or rotor downwash. [NASA drag equation](https://www1.grc.nasa.gov/beginners-guide-to-aeronautics/drag-equation/) and [coefficient limitations](https://www1.grc.nasa.gov/beginners-guide-to-aeronautics/drag-coefficient/) explain why area and matching flow conditions matter.

For comparison only, a +/-10 degree absolute pod-angle candidate, less 1.54 degrees common trim, leaves 8.46 degrees differential tilt. Near hover, ideal yaw moment is approximately m g d tan(delta) = **0.114 N m**, with d=0.117 m. This assumes coordinated thrust and no additional pitch/roll demand, actuator lag or saturation. The angle is not an implemented or flight-qualified limit.

| Crosswind m/s | Assumed C | Tail yaw N m | Fraction of ideal candidate |
|---:|---:|---:|---:|
| 3 | 1.0 | 0.007 | 6% |
| 3 | 1.5 | 0.011 | 9% |
| 5 | 1.0 | 0.020 | 17% |
| 5 | 1.5 | 0.029 | 26% |
| 8 | 1.0 | 0.050 | 44% |
| 8 | 1.5 | 0.075 | 66% |
| 10 | 1.0 | 0.078 | 69% |
| 10 | 1.5 | 0.117 | 103% |

The tail can consume a meaningful fraction of heading-control authority in crosswind. These calculations do not establish a safe wind speed, stability, damping, gust response or combined maneuver envelope. Tailplane pitch loads in forward flight/downwash, fin flow separation, vibration, rotor/fuselage interference, and full-aircraft aerodynamic moments remain unmodeled. A passive tail may tend to align the aircraft with relative wind; the active controller still has to hold the commanded heading.

## What must be checked on the prototype

- Weigh the completed tail and whole aircraft; measure CG with the actual battery and hardware. Rebalance toward x=0 and rerun the audit if any mass or geometry changes.
- Resolve and proof-load the internal tail splice/retention and long spine. Check resonance, flex, landing loads and fastener retention; no structural tail release is implied by a valid CAD solid.
- Measure side force/yaw torque and tailplane pitch loads in a restrained instrumented fixture across representative flow directions, including rotor-on effects. Compare to measured control authority with reserve for simultaneous commands.
- Verify firmware mixing, loaded servo response, motor thrust, vibration and loss-of-signal behavior before controlled flight qualification. Initial evaluation belongs in still air; no outdoor wind envelope is approved.

Run `python3 scripts/tail_audit.py` after `scripts/analyze.py` to regenerate this assessment.

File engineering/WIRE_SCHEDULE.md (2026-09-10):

# Neutral-installation wire schedule

Lengths follow modeled centerlines. Cut lengths add 15 mm termination allowance and 20 mm additional slack on each motor phase extension. Hand dress and measure before cutting final wires; routes are not a flexible harness simulation.

| Wire | Net | AWG | Route mm | Cut allowance mm | Endpoint functions |
|---|---|---:|---:|---:|---|
| L_ESC_VBAT | VBAT | 18 | 22 | 37 | Power splice + → ESC L + |
| L_ESC_GND | GND | 18 | 17 | 33 | Power splice - → ESC L - |
| L_Phase_0 | PHASE_L0 | 18 | 148 | 183 | ESC L phase0 → Motor L phase0 |
| L_Phase_1 | PHASE_L1 | 18 | 146 | 182 | ESC L phase1 → Motor L phase1 |
| L_Phase_2 | PHASE_L2 | 18 | 146 | 181 | ESC L phase2 → Motor L phase2 |
| L_Servo_0 | SERVO_L | 24 | 76 | 91 | Servo L → FC S9/S10 |
| L_Servo_1 | 6V_SERVO | 24 | 65 | 81 | Servo L → UBEC output |
| L_Servo_2 | GND | 24 | 66 | 82 | Servo L → UBEC output |
| L_ESC_signal | ESC_L | 26 | 30 | 45 | FC S1/S2 → ESC L signal |
| L_ESC_signal_ground | GND | 26 | 32 | 47 | FC GND → ESC L signal GND |
| R_ESC_VBAT | VBAT | 18 | 22 | 37 | Power splice + → ESC R + |
| R_ESC_GND | GND | 18 | 23 | 38 | Power splice - → ESC R - |
| R_Phase_0 | PHASE_R0 | 18 | 148 | 183 | ESC R phase0 → Motor R phase0 |
| R_Phase_1 | PHASE_R1 | 18 | 146 | 182 | ESC R phase1 → Motor R phase1 |
| R_Phase_2 | PHASE_R2 | 18 | 146 | 181 | ESC R phase2 → Motor R phase2 |
| R_Servo_0 | SERVO_R | 24 | 76 | 91 | Servo R → FC S9/S10 |
| R_Servo_1 | 6V_SERVO | 24 | 65 | 81 | Servo R → UBEC output |
| R_Servo_2 | GND | 24 | 66 | 82 | Servo R → UBEC output |
| R_ESC_signal | ESC_R | 26 | 30 | 45 | FC S1/S2 → ESC R signal |
| R_ESC_signal_ground | GND | 26 | 32 | 47 | FC GND → ESC R signal GND |
| Battery_stock_positive | VBAT | 14 | 14 | 29 | B1 pack + → XT60 battery half + |
| Battery_stock_negative | GND | 14 | 14 | 29 | B1 pack - → XT60 battery half - |
| B1_positive | VBAT | 14 | 121 | 137 | XT60 + → Power splice + |
| B1_negative | GND | 14 | 121 | 137 | XT60 - → Power splice - |
| UBEC_input_0 | VBAT | 22 | 104 | 119 | Power splice → UBEC input |
| FC_input_0 | VBAT | 26 | 35 | 51 | Power splice → FC battery input |
| Capacitor_0 | VBAT | 24 | 114 | 129 | Power splice → C1 |
| UBEC_input_1 | GND | 22 | 113 | 128 | Power splice → UBEC input |
| FC_input_1 | GND | 26 | 34 | 50 | Power splice → FC battery input |
| Capacitor_1 | GND | 24 | 118 | 134 | Power splice → C1 |
| Receiver_0 | 5V_FC | 26 | 25 | 41 | RP1 5V → FC 5V |
| Receiver_1 | GND | 26 | 25 | 41 | RP1 GND → FC GND |
| Receiver_2 | CRSF_TX | 26 | 25 | 41 | RP1 TX → FC RX2 |
| Receiver_3 | CRSF_RX | 26 | 25 | 41 | RP1 RX → FC TX2 |
| Balance_0 | CELL_TAP_0 | 26 | 19 | 35 | B1 balance tap → J2 pin 1 |
| Balance_1 | CELL_TAP_1 | 26 | 19 | 35 | B1 balance tap → J2 pin 2 |
| Balance_2 | CELL_TAP_2 | 26 | 19 | 35 | B1 balance tap → J2 pin 3 |
| Balance_3 | CELL_TAP_3 | 26 | 19 | 35 | B1 balance tap → J2 pin 4 |
| Balance_4 | CELL_TAP_4 | 26 | 19 | 35 | B1 balance tap → J2 pin 5 |
| Antenna_coax | RF | 30 | 75 | 90 | RP1 UFL → T antenna |
| Buzzer_wire_0 | BUZZER+ | 26 | 64 | 79 | Buzzer → FC buzzer pad |
| Buzzer_wire_1 | BUZZER- | 26 | 64 | 79 | Buzzer → FC buzzer pad |

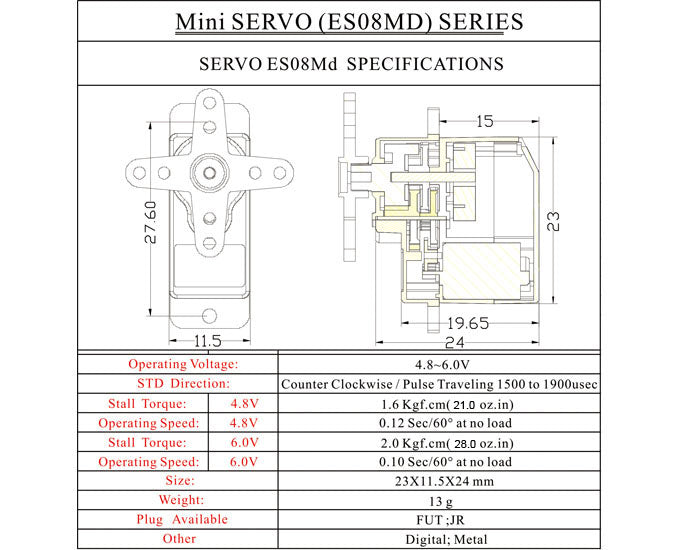
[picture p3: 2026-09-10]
source/servo_spec.jpg

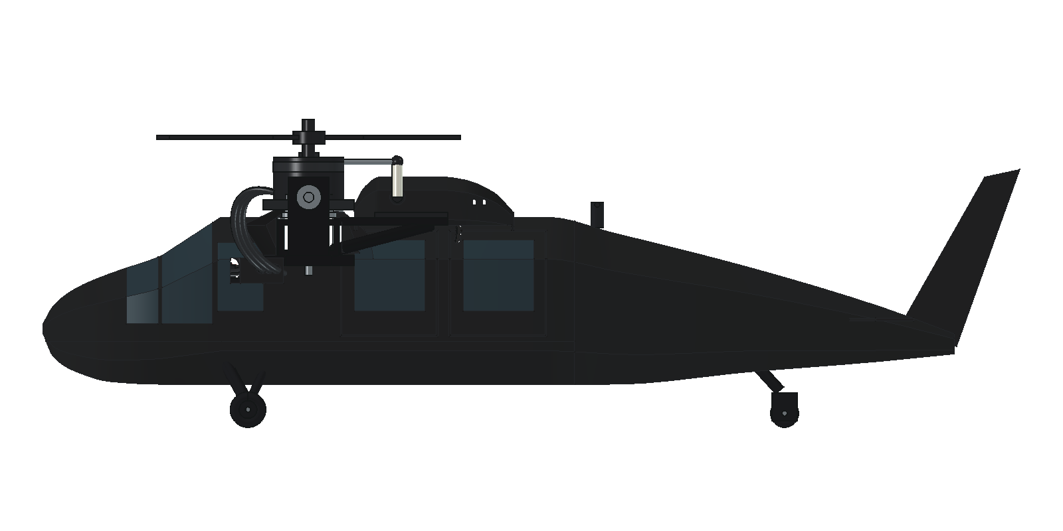
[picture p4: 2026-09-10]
images/profile.png

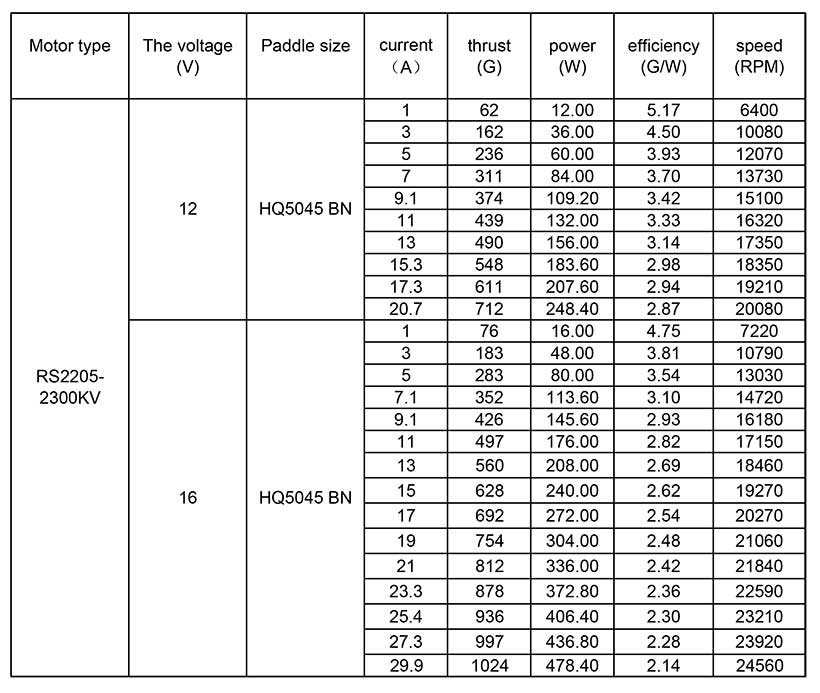
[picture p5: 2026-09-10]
source/motor_2.jpg

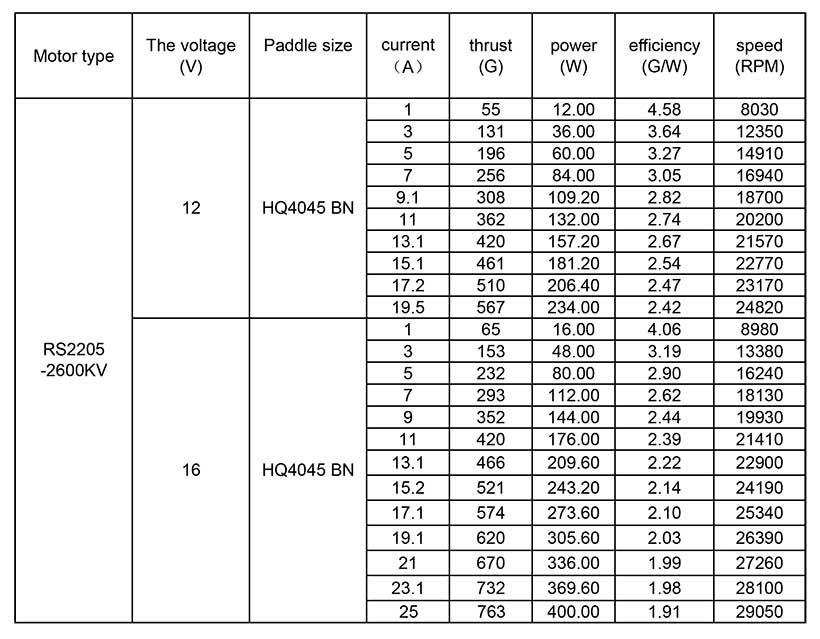
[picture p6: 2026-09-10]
source/motor_3.jpg

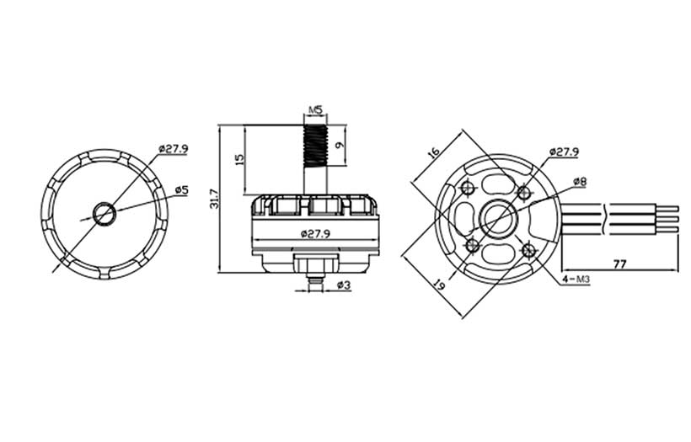
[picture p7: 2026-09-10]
source/motor_1.jpg

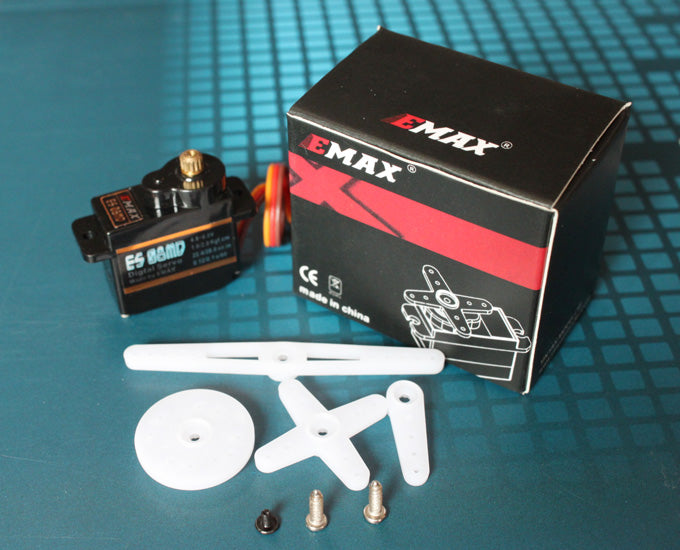
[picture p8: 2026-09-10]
source/servo_drawing.jpg

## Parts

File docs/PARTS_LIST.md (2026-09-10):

# Parts list - R4 fit prototype

No hardware has been purchased. This is a selection and allocation list, not a fully resolved purchase order. Vendor links are specification references; stock, prices and exact received dimensions are not guaranteed. Battery SKU, trunnion retention, mounting interfaces and loaded actuator performance must be resolved before an airworthy build.

## Purchased aircraft parts

| Qty | Item | Allocated total g | Selection / fit notes |
|---:|---|---:|---|
| 2 | [EMAX RS2205 2300KV motor](https://emaxmodel.com/products/emax-rs2205-racespec-motor-cooling-series) | 60.0 | Genuine original RS2205; 16 x 19 mm M3 mounting. Verify lead exit, shaft and screw engagement. |
| 2 | [HQProp HQ5045BN two-blade propeller](https://emaxmodel.com/products/emax-rs2205-racespec-motor-cooling-series) | 6.0 | One CW and one CCW; exact blade from thrust table. Buy commercial props; never print these. |
| 2 | [EMAX Lightning 30A ESC](https://shop.emaxmodel.com/products/emax-rs2205-2300kv-2600kv-racespec-brushless-motor-with-3-4s-30a-blheli-lightning-esc-power-combo) | 16.0 | Legacy BLHeli; 27 x 12 x 5 mm model reserve. Confirm actual dimensions, cooling and supported input protocol. |
| 2 | [Blue Bird BMS-115WV+ tilt servo](https://www.blue-bird-model.com/products_detail/55.htm) | 24.0 | 6 V; 23.2 x 10 x 23 mm body. Catalog 11 +/-0.5 g; 12 g planning allowance. Ears/spline stack provisional. |
| 1 | [Matek F405-TE flight controller](https://www.mateksys.com/?portfolio=f405-te) | 10.0 | 36 x 46 mm; verify 30.5 mm mount spacing and exact board variant. Bicopter firmware support required. |
| 1 | [Hobbywing UBEC 5A](https://www.hobbywing.com/en/products/ubec-5a93.html) | 21.0 | 50 x 17 x 10 mm; set to 6 V for servos only. 5 A continuous rating; actual simultaneous servo demand unknown. |
| 1 | [RadioMaster RP1 V2 ELRS 2.4 GHz receiver](https://www.radiomasterrc.com/products/rp1-expresslrs-2-4ghz-nano-receiver) | 2.2 | 13 x 11 x 3 mm, antenna included in allocation. Requires compatible ELRS transmitter; FlySky AFHDS radio is not compatible. |
| 1 | [4S 1300 mAh LiPo - exact SKU OPEN](https://www.genstattu.com/blog/tattu-fpv-battery-recommend) | 170.0 | 76 x 38 x 31 mm maximum planning envelope, including stock leads in mass. Must support measured pack current and fit; no C-label guarantee. |
| 1 | XT60 aircraft-side connector | 4.0 | Mate to battery connector; insulated solder cups and strain relief. Stock battery half is counted with battery. |
| 1 | 470 uF 35 V low-ESR capacitor | 3.0 | Reserve diameter 10 x 16 mm; confirm ripple rating and polarity. Lead length affects suppression. |
| 1 | 5 V active buzzer | 2.0 | Reserve diameter 10 x 5 mm; verify compatibility with FC buzzer output and polarity. |
| 4 | MR104 bearing, 4 x 10 x 4 mm | 5.2 | Metal bearings; confirm fit, shields, axial support and smooth rotation. |
| 4 | 4 mm metal trunnion / shoulder pin | 8.0 | Nominal 14 mm modeled length. Final shoulders, spacers, retaining method and bearing stack OPEN. |
| 2 | [OEM-compatible 25T servo horn](https://www.blue-bird-model.com/products_detail/55.htm) | 1.6 | 14 mm effective pivot-to-ball radius. Verify spline and screw; do not substitute a loose printed spline. |
| 2 | M2 pushrod with ball-link ends | 4.0 | 35 mm center-to-center modeled link; four ball joints total. Verify travel, clearance and attachment geometry. |

Purchased allocations total **337.0 g**. Wires, solder, remaining connectors and small installation hardware are allocated below, not added again to the above component envelopes.

## Installation materials and unresolved hardware

| Allowance | Budget g | Contents |
|---|---:|---|
| Harness and secondary connectors | 36 | Silicone wire by schedule; insulation, solder, servo plugs and power splice. Existing stock leads may cover some modeled lengths. |
| Fasteners, spacers and retention | 25 | M3/M2 screws, nuts, washers, FC grommets, wheel axles and pin retainers. Final stack and retention are not released. |
| Straps, foam, ties and insulation | 8 | Two nominal 10 mm battery straps; battery pad, FC isolation and strain relief. |
| Adhesive and light finish | 8 | Tail/shell joints and restrained matte-black finish. Verify adhesion/material and count actual paint mass. |

Initial modeled screw schedule: 8 motor M3 screws with 7 mm under-head length, 4 FC M3 x10, 4 beam/keel M3 x22, 4 yoke M3 x10, two diameter-2 x12 mm main wheel axles and one diameter-2 x9 mm tailwheel axle. These are CAD dimensions, not approved screw lengths: check motor winding clearance, printed wall engagement, nuts and washers before use. Four FC isolators and four ball-link ends are represented; avoid double-counting ends already supplied with link assemblies. Servo ear screws, tail splice, shell closure and trunnion retention still require final detailing.

Wire sizes: 14 AWG main power, 18 AWG ESC supply and motor phases, 22 AWG UBEC input, 24 AWG servo supply/signals and capacitor leads, 26 AWG low-current FC/RX signals. Use the [42-route wire schedule](../engineering/WIRE_SCHEDULE.md) for modeled lengths and termination allowances. Antenna coax and battery balance leads represent supplied assemblies, not an instruction to fabricate RF antennas or modify the pack.

## Print list

One of each installed STL; 40 pieces total. Names identify mirrored and separated pieces explicitly. Two optional guards add 25.4 g and are omitted from the baseline mass. All masses below assume the full CAD material volume at 1.24 g/cm^3; these are not slicer predictions. All mesh bounds fit the 256 mm printer cube, but orientation, supports, brim and tolerances must be checked in the slicer.

| STL / part | Qty | CAD mass g | Bounding box mm |
|---|---:|---:|---|
| [P01_Battery_keel](../stl/P01_Battery_keel.stl) | 1 | 35.28 | 136.0 x 58.0 x 48.0 |
| [P02_Crossbeam](../stl/P02_Crossbeam.stl) | 1 | 45.18 | 73.0 x 168.0 x 19.0 |
| [P03_Avionics_deck](../stl/P03_Avionics_deck.stl) | 1 | 6.30 | 54.0 x 49.0 x 4.0 |
| [P09_Cabin_side_glazing_0](../stl/P09_Cabin_side_glazing_0.stl) | 1 | 0.53 | 18.0 x 4.5 x 27.0 |
| [P09_Cabin_side_glazing_0_segment_2](../stl/P09_Cabin_side_glazing_0_segment_2.stl) | 1 | 1.10 | 28.0 x 4.8 x 28.0 |
| [P09_Cabin_side_glazing_0_segment_3](../stl/P09_Cabin_side_glazing_0_segment_3.stl) | 1 | 1.03 | 28.0 x 5.3 x 28.0 |
| [P09_Cabin_side_glazing_1](../stl/P09_Cabin_side_glazing_1.stl) | 1 | 0.53 | 18.0 x 4.5 x 27.0 |
| [P09_Cabin_side_glazing_1_segment_2](../stl/P09_Cabin_side_glazing_1_segment_2.stl) | 1 | 1.10 | 28.0 x 4.8 x 28.0 |
| [P09_Cabin_side_glazing_1_segment_3](../stl/P09_Cabin_side_glazing_1_segment_3.stl) | 1 | 1.03 | 28.0 x 5.3 x 28.0 |
| [P06_Cabin_upper](../stl/P06_Cabin_upper.stl) | 1 | 25.70 | 210.0 x 62.0 x 51.0 |
| [P07_Cabin_lower](../stl/P07_Cabin_lower.stl) | 1 | 22.95 | 208.8 x 62.0 x 17.0 |
| [P08_Windshield](../stl/P08_Windshield.stl) | 1 | 1.45 | 20.0 x 29.9 x 40.0 |
| [P08_Windshield_segment_2](../stl/P08_Windshield_segment_2.stl) | 1 | 0.74 | 12.5 x 28.8 x 26.3 |
| [P08_Windshield_segment_3](../stl/P08_Windshield_segment_3.stl) | 1 | 1.45 | 20.0 x 29.9 x 40.0 |
| [P08_Windshield_segment_4](../stl/P08_Windshield_segment_4.stl) | 1 | 0.74 | 12.5 x 28.8 x 26.3 |
| [P19_Tapered_tail_boom](../stl/P19_Tapered_tail_boom.stl) | 1 | 22.77 | 150.0 x 56.6 x 64.5 |
| [P04_Tail_spine](../stl/P04_Tail_spine.stl) | 1 | 3.15 | 163.3 x 12.0 x 35.5 |
| [P05_Vertical_tail_fin](../stl/P05_Vertical_tail_fin.stl) | 1 | 2.19 | 52.0 x 1.3 x 70.0 |
| [P05_Horizontal_tailplane](../stl/P05_Horizontal_tailplane.stl) | 1 | 1.64 | 31.0 x 48.0 x 1.2 |
| [P17_Shoulder_cowl__1](../stl/P17_Shoulder_cowl__1.stl) | 1 | 4.32 | 46.0 x 52.0 x 20.0 |
| [P20_Servo_engine_cowl__1](../stl/P20_Servo_engine_cowl__1.stl) | 1 | 4.33 | 63.0 x 30.4 x 21.0 |
| [P22_Cable_raceway__1](../stl/P22_Cable_raceway__1.stl) | 1 | 4.03 | 17.0 x 54.0 x 10.0 |
| [P10_Main_gear__1](../stl/P10_Main_gear__1.stl) | 1 | 1.28 | 27.7 x 17.5 x 26.7 |
| [P23_Main_wheel__1](../stl/P23_Main_wheel__1.stl) | 1 | 0.64 | 14.0 x 4.0 x 14.0 |
| [P17_Shoulder_cowl_1](../stl/P17_Shoulder_cowl_1.stl) | 1 | 4.32 | 46.0 x 52.0 x 20.0 |
| [P20_Servo_engine_cowl_1](../stl/P20_Servo_engine_cowl_1.stl) | 1 | 4.33 | 63.0 x 30.4 x 21.0 |
| [P22_Cable_raceway_1](../stl/P22_Cable_raceway_1.stl) | 1 | 4.03 | 17.0 x 54.0 x 10.0 |
| [P10_Main_gear_1](../stl/P10_Main_gear_1.stl) | 1 | 1.28 | 27.7 x 17.5 x 26.7 |
| [P23_Main_wheel_1](../stl/P23_Main_wheel_1.stl) | 1 | 0.64 | 14.0 x 4.0 x 14.0 |
| [P24_Tailwheel_fork](../stl/P24_Tailwheel_fork.stl) | 1 | 0.82 | 19.6 x 7.0 x 25.5 |
| [P25_Tailwheel](../stl/P25_Tailwheel.stl) | 1 | 0.29 | 11.0 x 3.0 x 11.0 |
| [P11_L_bearing_yoke](../stl/P11_L_bearing_yoke.stl) | 1 | 10.64 | 18.0 x 74.0 x 35.0 |
| [P12_L_motor_cradle](../stl/P12_L_motor_cradle.stl) | 1 | 10.37 | 36.0 x 85.0 x 22.5 |
| [P13_L_tilting_guard](../stl/optional_guards/P13_L_tilting_guard.stl) (optional) | 1 | 12.68 | 142.2 x 142.2 x 32.7 |
| [P14_L_servo_retainer](../stl/P14_L_servo_retainer.stl) | 1 | 0.60 | 29.0 x 30.0 x 2.5 |
| [P15_L_ESC_tray](../stl/P15_L_ESC_tray.stl) | 1 | 1.22 | 31.0 x 16.0 x 2.0 |
| [P11_R_bearing_yoke](../stl/P11_R_bearing_yoke.stl) | 1 | 10.64 | 18.0 x 74.0 x 35.0 |
| [P12_R_motor_cradle](../stl/P12_R_motor_cradle.stl) | 1 | 10.37 | 36.0 x 85.0 x 22.5 |
| [P13_R_tilting_guard](../stl/optional_guards/P13_R_tilting_guard.stl) (optional) | 1 | 12.68 | 142.2 x 142.2 x 32.7 |
| [P14_R_servo_retainer](../stl/P14_R_servo_retainer.stl) | 1 | 0.60 | 29.0 x 30.0 x 2.5 |
| [P15_R_ESC_tray](../stl/P15_R_ESC_tray.stl) | 1 | 1.22 | 31.0 x 16.0 x 2.0 |
| [P16_Antenna_mast](../stl/P16_Antenna_mast.stl) | 1 | 0.10 | 5.0 x 5.0 x 10.0 |

## Ground equipment - excluded from flight mass

- ELRS 2.4 GHz transmitter or a compatible transmitter/module combination.
- LiPo balance charger supporting 4S, suitable supply and charging accessories.
- Scale with gram resolution, calipers, multimeter and current/voltage logging.
- Restrained thrust stand, protected actuator/load fixture and vibration measurement.
- Soldering equipment, heat-shrink, drivers and bearing/fastener fit coupons.
- Suitable filament and slicer for Centauri Carbon; qualify the actual material/process on loaded and heated joints.

Commercial propellers, motors, bearings, metal pins, fasteners and servo gears remain purchased parts. More printing does not justify unqualified rotating blades or unreliable pivots.

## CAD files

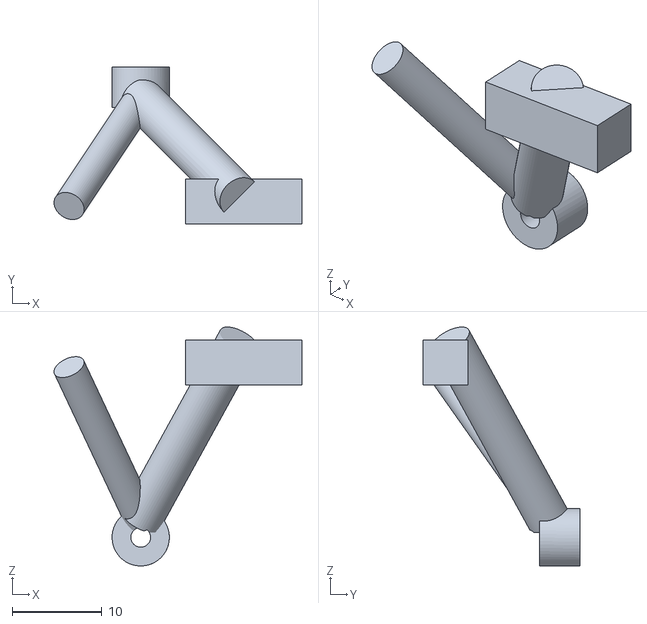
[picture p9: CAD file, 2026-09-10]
stl/P10_Main_gear_1.stl
27.7 x 17.5 x 26.7

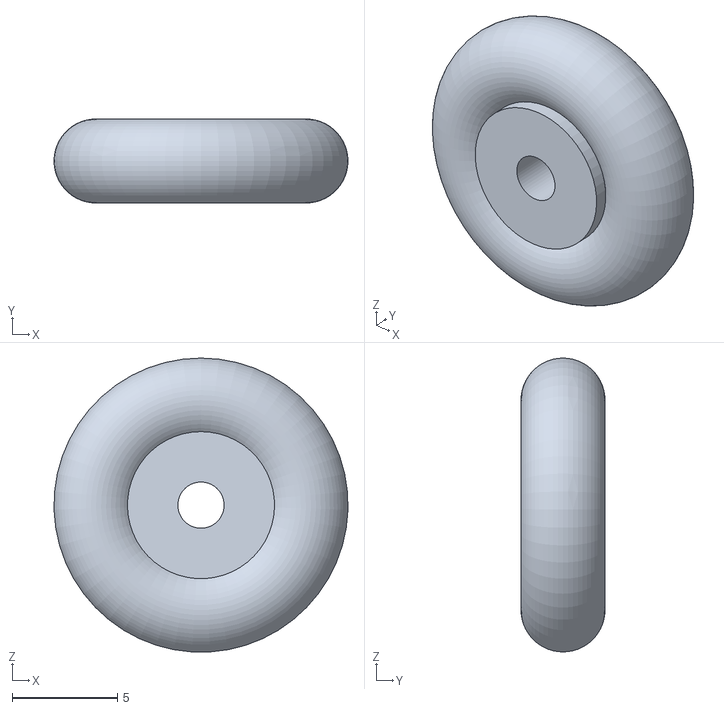
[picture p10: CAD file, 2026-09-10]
stl/P23_Main_wheel_1.stl
14.0 x 4.00 x 14.0

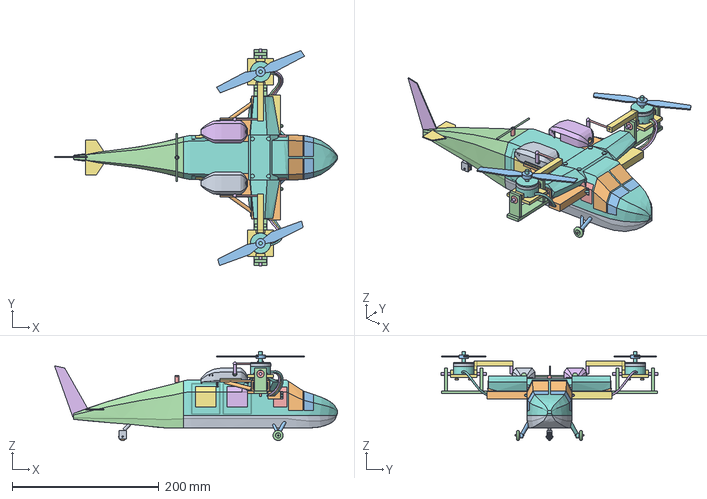
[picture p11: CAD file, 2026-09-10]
cad/Kestrel_Mini_R4.step
386.0 x 296.0 x 121.7 mm

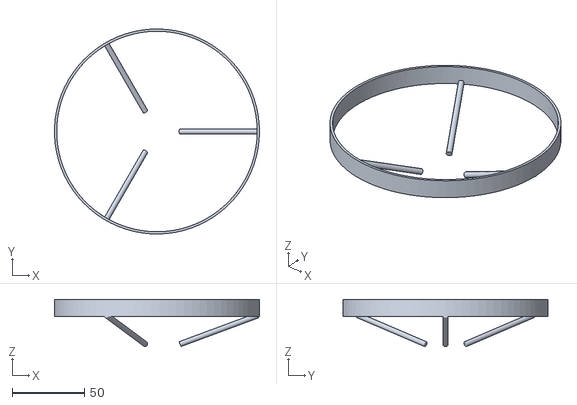
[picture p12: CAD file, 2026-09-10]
stl/optional_guards/P13_R_tilting_guard.stl
142.1 x 142.2 x 32.7

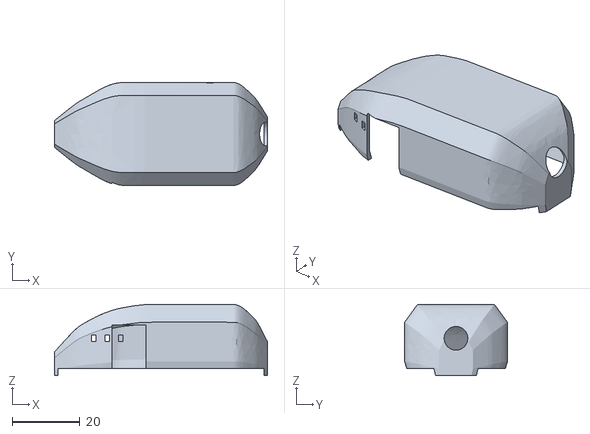
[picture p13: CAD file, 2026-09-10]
stl/P20_Servo_engine_cowl_1.stl
63.0 x 30.4 x 21.0

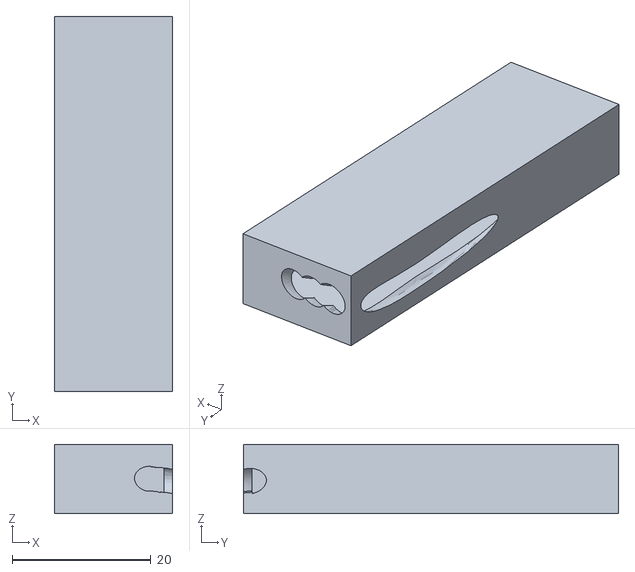
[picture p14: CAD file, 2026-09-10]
stl/P22_Cable_raceway_1.stl
17.0 x 54.0 x 10.0

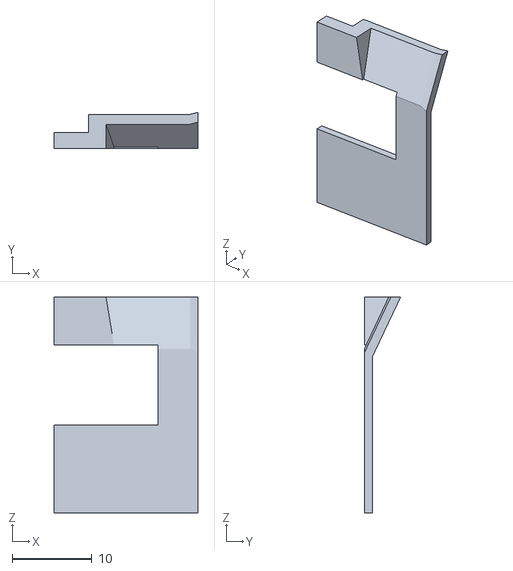
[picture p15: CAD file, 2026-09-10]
stl/P09_Cabin_side_glazing_0.stl
18.0 x 4.55 x 27.0

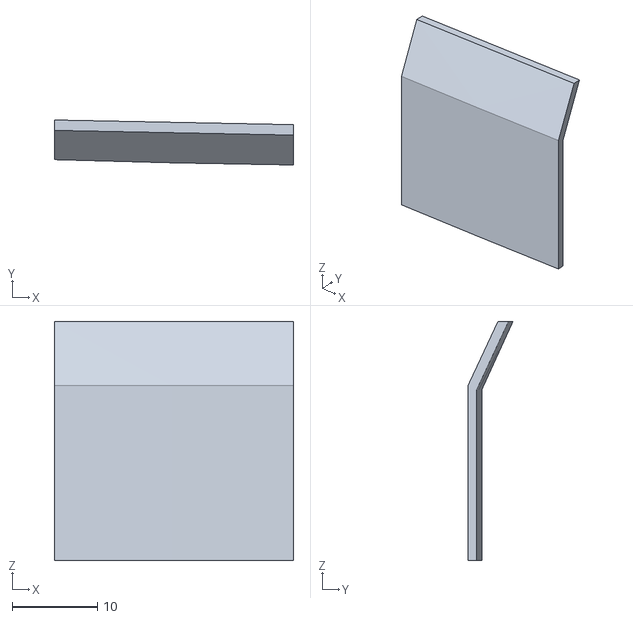
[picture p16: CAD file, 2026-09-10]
stl/P09_Cabin_side_glazing_0_segment_3.stl
28.0 x 5.28 x 28.0

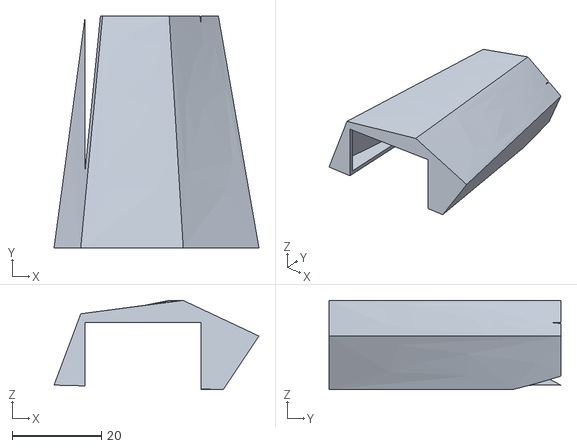
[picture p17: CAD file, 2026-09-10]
stl/P17_Shoulder_cowl_1.stl
46.0 x 52.0 x 20.0

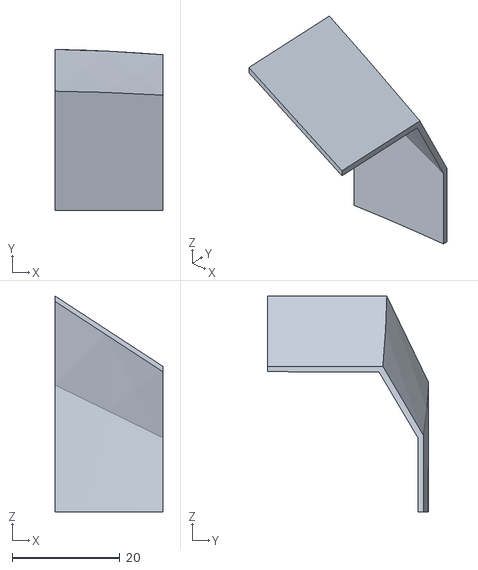
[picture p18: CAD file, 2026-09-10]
stl/P08_Windshield_segment_3.stl
20.0 x 29.9 x 40.0

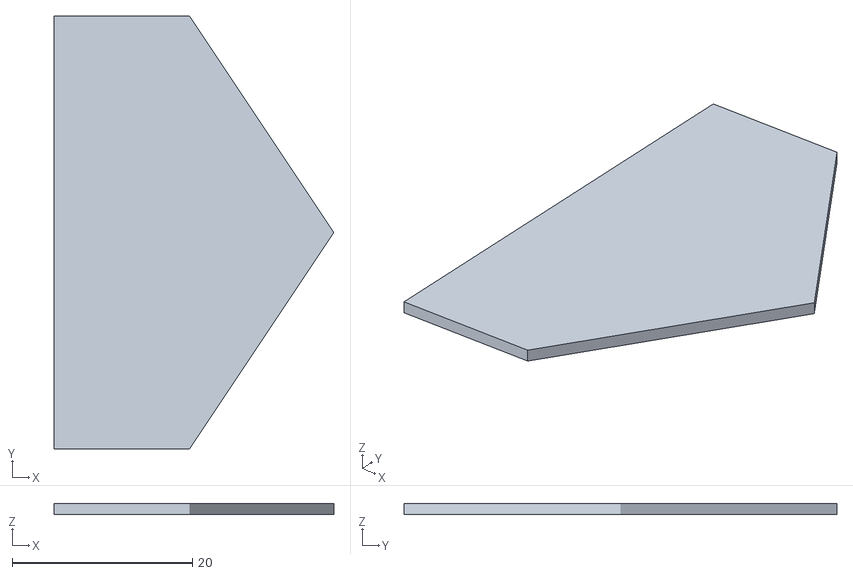
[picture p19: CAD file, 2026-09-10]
stl/P05_Horizontal_tailplane.stl
31.0 x 48.0 x 1.20

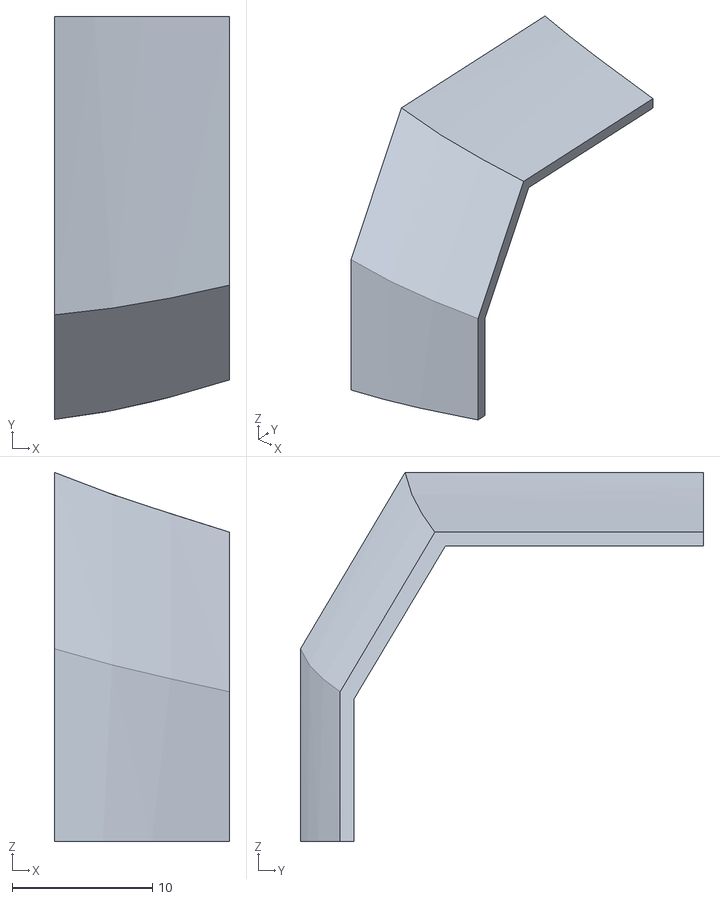
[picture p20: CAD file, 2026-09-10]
stl/P08_Windshield_segment_2.stl
12.5 x 28.8 x 26.3

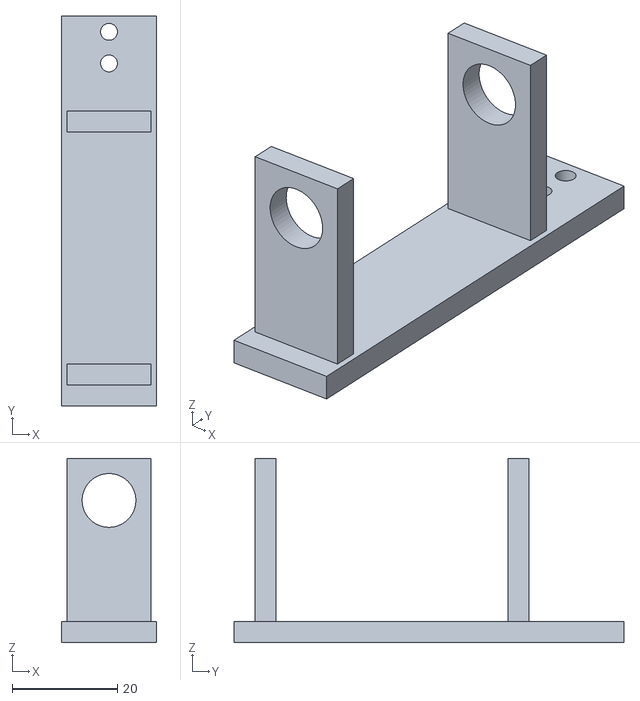
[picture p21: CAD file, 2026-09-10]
stl/P11_R_bearing_yoke.stl
18.0 x 74.0 x 35.0

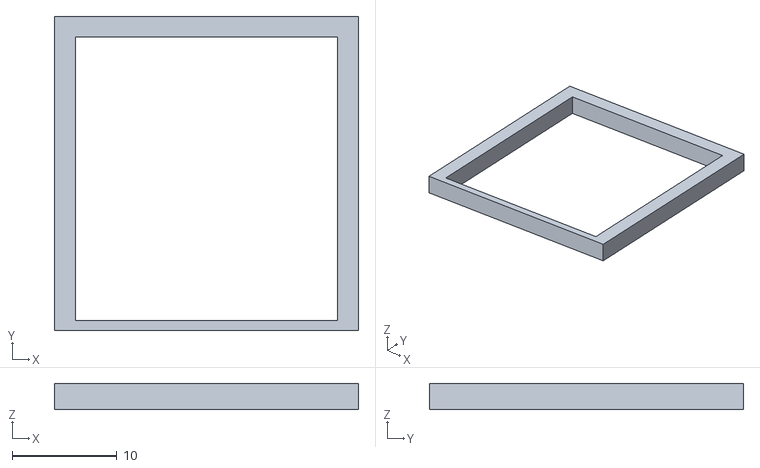
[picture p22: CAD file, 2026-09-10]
stl/P14_L_servo_retainer.stl
29.0 x 30.0 x 2.50

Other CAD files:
stl/optional_guards/P13_L_tilting_guard.stl
stl/P07_Cabin_lower.stl
stl/P15_R_ESC_tray.stl
stl/P05_Vertical_tail_fin.stl
cad/Kestrel_Mini_R4.FCStd
stl/P01_Battery_keel.stl
stl/P02_Crossbeam.stl
stl/P03_Avionics_deck.stl
stl/P04_Tail_spine.stl
stl/P06_Cabin_upper.stl
stl/P08_Windshield.stl
stl/P08_Windshield_segment_4.stl
stl/P09_Cabin_side_glazing_0_segment_2.stl
stl/P09_Cabin_side_glazing_1.stl
stl/P09_Cabin_side_glazing_1_segment_2.stl
stl/P09_Cabin_side_glazing_1_segment_3.stl
stl/P10_Main_gear__1.stl
stl/P11_L_bearing_yoke.stl
stl/P12_L_motor_cradle.stl
stl/P12_R_motor_cradle.stl
stl/P14_R_servo_retainer.stl
stl/P15_L_ESC_tray.stl
stl/P16_Antenna_mast.stl
stl/P17_Shoulder_cowl__1.stl
stl/P19_Tapered_tail_boom.stl
stl/P20_Servo_engine_cowl__1.stl
stl/P22_Cable_raceway__1.stl
stl/P24_Tailwheel_fork.stl
stl/P25_Tailwheel.stl

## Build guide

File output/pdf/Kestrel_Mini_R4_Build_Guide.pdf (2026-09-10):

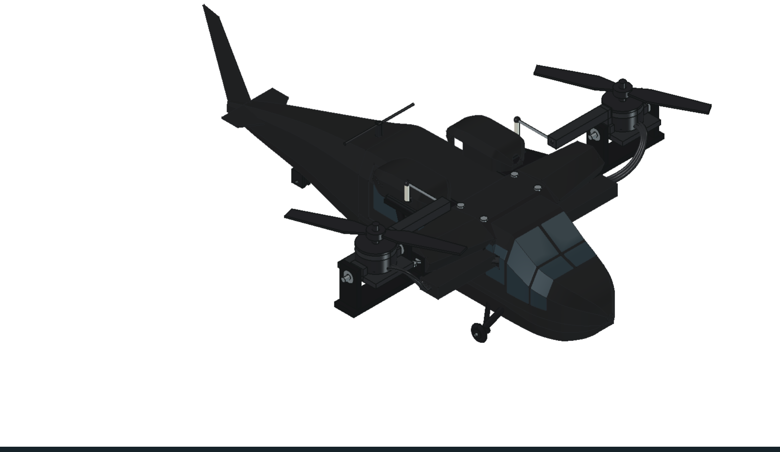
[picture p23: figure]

KESTREL MINI R4 / DESIGN PROTOTYPE / 2026-09-09 | 1

01 / KESTREL MINI R4

# Build & engineering guide

# KESTREL MINI R4

Black Hawk inspired styling. Two independently tilting lift pods.

NOMINAL MASS | WITH 10% GROWTH | INSTALLED PRINTS
665 g | 731 g | 40 pieces

Design / fit prototype - flight qualification remains open. The CAD includes electronics, wiring and a lightweight tail. Published motor data support takeoff in theory under the stated assumptions; the aircraft has not been built or flown.

Revision R4 | 9 September 2026 | Units: mm, g, N and N m. Baseline uses a 4S1300 LiPo, commercial 5-inch props and no optional
guards.

# Purchase list / electronics

No hardware is owned. These selections establish the CAD and calculation basis. Buy only after resolving the marked interfaces; a similar-looking substitute invalidates the existing fit or thrust evidence. Reference IDs link to manufacturer pages on page 13.

Qty | Selected part | Total g | Key fit / selection requirement
2 | EMAX RS2205 2300KV motor [MOTOR] | 60.0 | Genuine original RS2205; 16 x 19 mm M3 mounting. Verify lead exit, shaft and screw engagement.
2 | HQProp HQ5045BN two-blade propeller [MOTOR] | 6.0 | One CW and one CCW; exact blade from thrust table. Buy commercial props; never print these.
2 | EMAX Lightning 30A ESC [ESC] | 16.0 | Legacy BLHeli; 27 x 12 x 5 mm model reserve. Confirm actual dimensions, cooling and supported input protocol.
2 | Blue Bird BMS-115WV+ tilt servo [SERVO] | 24.0 | 6 V; 23.2 x 10 x 23 mm body. Catalog 11 +/-0.5 g; 12 g planning allowance. Ears/spline stack provisional.
1 | Matek F405-TE flight controller [FC] | 10.0 | 36 x 46 mm; verify 30.5 mm mount spacing and exact board variant. Bicopter firmware support required.
1 | Hobbywing UBEC 5A [BEC] | 21.0 | 50 x 17 x 10 mm; set to 6 V for servos only. 5 A continuous rating; actual simultaneous servo demand unknown.
1 | RadioMaster RP1 V2 ELRS 2.4 GHz receiver [RX] | 2.2 | 13 x 11 x 3 mm, antenna included in allocation. Requires compatible ELRS transmitter; FlySky AFHDS radio is not compatible.
1 | 4S 1300 mAh LiPo - exact SKU OPEN [BATTERY] | 170.0 | 76 x 38 x 31 mm maximum planning envelope, including stock leads in mass. Must support measured pack current and fit; no C-label guarantee.
1 | XT60 aircraft-side connector | 4.0 | Mate to battery connector; insulated solder cups and strain relief. Stock battery half is counted with battery.
1 | 470 uF 35 V low-ESR capacitor | 3.0 | Reserve diameter 10 x 16 mm; confirm ripple rating and polarity. Lead length affects suppression.
1 | 5 V active buzzer | 2.0 | Reserve diameter 10 x 5 mm; verify compatibility with FC buzzer output and polarity.

Battery selection is OPEN. The 170 g allocation includes stock leads; confirm actual pack current capability, mass and dimensions. Four 21700 cells would put this layout near 799 g before contingency and require packaging changes.

# Mechanical parts & bench equipment

Qty | Purchased mechanical part | Total g | Interface requirement
4 | MR104 bearing, 4 x 10 x 4 mm | 5.2 | Metal bearings; confirm fit, shields, axial support and smooth rotation.
4 | 4 mm metal trunnion / shoulder pin | 8.0 | Nominal 14 mm modeled length. Final shoulders, spacers, retaining method and bearing stack OPEN.
2 | OEM-compatible 25T servo horn | 1.6 | 14 mm effective pivot-to-ball radius. Verify spline and screw; do not substitute a loose printed spline.
2 | M2 pushrod with ball-link ends | 4.0 | 35 mm center-to-center modeled link; four ball joints total. Verify travel, clearance and attachment geometry.

## Installation allowances - 77 g total

Budget | Included material | | g
Harness | Wire, solder, secondary connectors, insulated power splice | 36
Hardware | Other screws, nuts, spacers, isolators, axles and retainers | 25
Installation | Straps, foam, ties and insulation | 8
Finish | Adhesive and restrained matte-black finish | 8

Modeled fastener dimensions: eight motor M3 x7, four FC M3 x10, four beam/keel M3 x22, four yoke M3 x10; two diameter-2 x12 mm main axles and one diameter-2 x9 mm tail axle. Lengths require received-hardware verification. Motor screw ends must clear windings. Tail splice, shell closure, servo ear screws and trunnion retention are not fully detailed.

## Ground equipment - outside aircraft mass

- ELRS 2.4 GHz transmitter/module compatible with RP1; the initial FlySky radio suggestion does not match this receiver.
- 4S-compatible LiPo balance charger and supply; scale, calipers, multimeter, current/voltage logging and soldering tools.
- Restrained thrust and actuator test fixtures, vibration measurement, fit coupons and appropriate filament/slicer.

Purchased component allocations total 337 g. Do not count supplied horns, link ends, battery connectors or stock leads twice. Exact hardware is still a fit and qualification task.

# Print inventory / 1 of 2

One of each listed STL. Names correspond exactly to files in stl/. Separated glazing pieces and mirrored parts have individual files. CAD masses use full material volume at 1.24 g/cm^3; confirm slicer mass and actual print weight.

STL name (without .stl) | CAD g | Bounding box, mm
P01_Battery_keel | 35.28 | 136.0 x 58.0 x 48.0
P02_Crossbeam | 45.18 | 73.0 x 168.0 x 19.0
P03_Avionics_deck | 6.30 | 54.0 x 49.0 x 4.0
P04_Tail_spine | 3.15 | 163.3 x 12.0 x 35.5
P05_Horizontal_tailplane | 1.64 | 31.0 x 48.0 x 1.2
P05_Vertical_tail_fin | 2.19 | 52.0 x 1.3 x 70.0
P06_Cabin_upper | 25.70 | 210.0 x 62.0 x 51.0
P07_Cabin_lower | 22.95 | 208.8 x 62.0 x 17.0
P08_Windshield | 1.45 | 20.0 x 29.9 x 40.0
P08_Windshield_segment_2 | 0.74 | 12.5 x 28.8 x 26.3
P08_Windshield_segment_3 | 1.45 | 20.0 x 29.9 x 40.0
P08_Windshield_segment_4 | 0.74 | 12.5 x 28.8 x 26.3
P09_Cabin_side_glazing_0 | 0.53 | 18.0 x 4.5 x 27.0
P09_Cabin_side_glazing_0_segment_2 | 1.10 | 28.0 x 4.8 x 28.0
P09_Cabin_side_glazing_0_segment_3 | 1.03 | 28.0 x 5.3 x 28.0
P09_Cabin_side_glazing_1 | 0.53 | 18.0 x 4.5 x 27.0
P09_Cabin_side_glazing_1_segment_2 | 1.10 | 28.0 x 4.8 x 28.0
P09_Cabin_side_glazing_1_segment_3 | 1.03 | 28.0 x 5.3 x 28.0
P10_Main_gear_1 | 1.28 | 27.7 x 17.5 x 26.7
P10_Main_gear__1 | 1.28 | 27.7 x 17.5 x 26.7

# Print inventory / 2 of 2

One of each listed STL. Names correspond exactly to files in stl/. Separated glazing pieces and mirrored parts have individual files. CAD masses use full material volume at 1.24 g/cm^3; confirm slicer mass and actual print weight.

STL name (without .stl) | CAD g | Bounding box, mm
P11_L_bearing_yoke | 10.64 | 18.0 x 74.0 x 35.0
P11_R_bearing_yoke | 10.64 | 18.0 x 74.0 x 35.0
P12_L_motor_cradle | 10.37 | 36.0 x 85.0 x 22.5
P12_R_motor_cradle | 10.37 | 36.0 x 85.0 x 22.5
P14_L_servo_retainer | 0.60 | 29.0 x 30.0 x 2.5
P14_R_servo_retainer | 0.60 | 29.0 x 30.0 x 2.5
P15_L_ESC_tray | 1.22 | 31.0 x 16.0 x 2.0
P15_R_ESC_tray | 1.22 | 31.0 x 16.0 x 2.0
P16_Antenna_mast | 0.10 | 5.0 x 5.0 x 10.0
P17_Shoulder_cowl_1 | 4.32 | 46.0 x 52.0 x 20.0
P17_Shoulder_cowl__1 | 4.32 | 46.0 x 52.0 x 20.0
P19_Tapered_tail_boom | 22.77 | 150.0 x 56.6 x 64.5
P20_Servo_engine_cowl_1 | 4.33 | 63.0 x 30.4 x 21.0
P20_Servo_engine_cowl__1 | 4.33 | 63.0 x 30.4 x 21.0
P22_Cable_raceway_1 | 4.03 | 17.0 x 54.0 x 10.0
P22_Cable_raceway__1 | 4.03 | 17.0 x 54.0 x 10.0
P23_Main_wheel_1 | 0.64 | 14.0 x 4.0 x 14.0
P23_Main_wheel__1 | 0.64 | 14.0 x 4.0 x 14.0
P24_Tailwheel_fork | 0.82 | 19.6 x 7.0 x 25.5
P25_Tailwheel | 0.29 | 11.0 x 3.0 x 11.0

## Optional guards - omitted from baseline

STL name | CAD g | Bounding box, mm
P13_L_tilting_guard | 12.68 | 142.2 x 142.2 x 32.7
P13_R_tilting_guard | 12.68 | 142.2 x 142.2 x 32.7

Installed printed mass: 250.90 g. Optional guards add 25.37 g. All 42 meshes fit the printer cube by bounding box; brim, supports and print orientation still need a slicer check.

# Power & control wiring

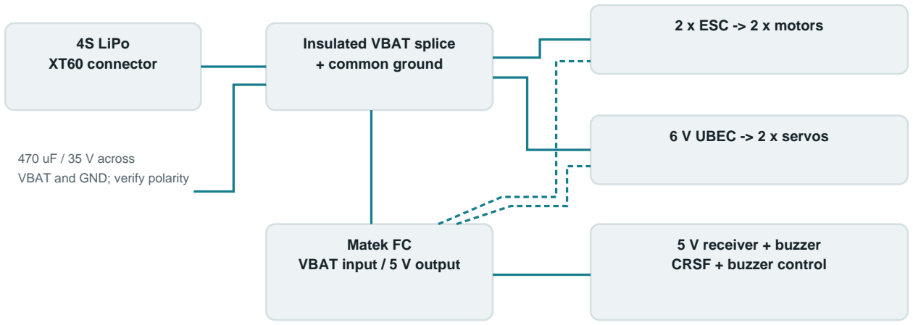
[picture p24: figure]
4S LiPo XT60 connector; Insulated VBAT splice + common ground; 2 x ESC -> 2 x motors; 6 V UBEC -> 2 x servos; Matek FC VBAT input / 5 V output; 5 V receiver + buzzer CRSF + buzzer control; 470 uF / 35 V across VBAT and GND; verify polarity

Dashed: FC control signals. All grounds common; keep 5 V and 6 V positives separate.

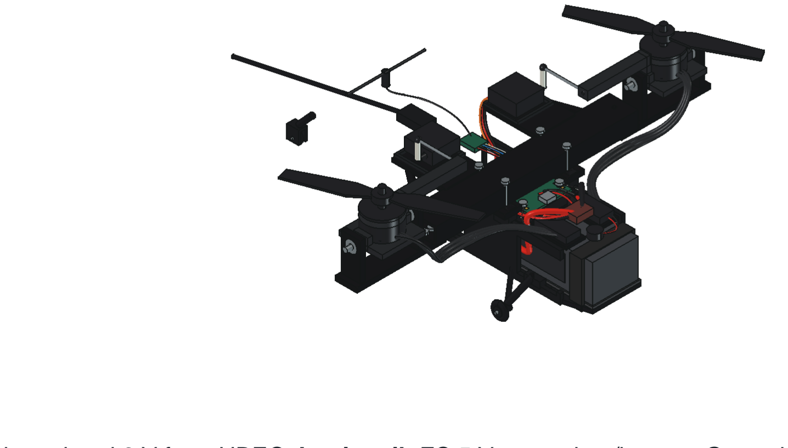
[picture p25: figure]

Servo rail: dedicated regulated 6 V from UBEC. Logic rail: FC 5 V to receiver/buzzer. Grounds are common; do not join positive regulated rails. Main motor current bypasses the FC current sensor in this layout, so total pack current needs external measurement.

Proposed FC resources: S1/PC9 and S2/PC8 motors; S9/PB14 and S10/PA6 tilt servos. CRSF uses RX2/PA3 and TX2/PA2. Confirm actual firmware target, servo support, BI mixer, direction, neutral, endpoints and protocol with props removed. Older ESCs are not assumed to support DShot.

# Wire schedule / 1 of 2

Neutral modeled paths. Cut estimate adds 15 mm for terminations and another 20 mm on each phase extension. Existing motor, servo and battery leads may replace extensions; hand dress and measure first. Endpoint names indicate function, not exact solder-pad geometry.

Wire | AWG | Route / cut mm | Endpoint functions
L_ESC_VBAT | 18 | 22 / 37 | Power splice + -> ESC L +
L_ESC_GND | 18 | 17 / 33 | Power splice - -> ESC L -
L_Phase_0 | 18 | 148 / 183 | ESC L phase0 -> Motor L phase0
L_Phase_1 | 18 | 146 / 182 | ESC L phase1 -> Motor L phase1
L_Phase_2 | 18 | 146 / 181 | ESC L phase2 -> Motor L phase2
L_Servo_0 | 24 | 76 / 91 | Servo L -> FC S9/S10
L_Servo_1 | 24 | 65 / 81 | Servo L -> UBEC output
L_Servo_2 | 24 | 66 / 82 | Servo L -> UBEC output
L_ESC_signal | 26 | 30 / 45 | FC S1/S2 -> ESC L signal
L_ESC_signal_ground | 26 | 32 / 47 | FC GND -> ESC L signal GND
R_ESC_VBAT | 18 | 22 / 37 | Power splice + -> ESC R +
R_ESC_GND | 18 | 23 / 38 | Power splice - -> ESC R -
R_Phase_0 | 18 | 148 / 183 | ESC R phase0 -> Motor R phase0
R_Phase_1 | 18 | 146 / 182 | ESC R phase1 -> Motor R phase1
R_Phase_2 | 18 | 146 / 181 | ESC R phase2 -> Motor R phase2
R_Servo_0 | 24 | 76 / 91 | Servo R -> FC S9/S10
R_Servo_1 | 24 | 65 / 81 | Servo R -> UBEC output
R_Servo_2 | 24 | 66 / 82 | Servo R -> UBEC output
R_ESC_signal | 26 | 30 / 45 | FC S1/S2 -> ESC R signal
R_ESC_signal_ground | 26 | 32 / 47 | FC GND -> ESC R signal GND
Battery_stock_positive | 14 | 14 / 29 | B1 pack + -> XT60 battery half +

42 routes are modeled and checked at neutral. Flexible travel, wire fatigue, wire-to-wire contact and every terminal/electronics pair are not continuously verified. Supplied antenna coax and pack balance leads are reference assemblies; do not fabricate or cut them from this table.

# Wire schedule / 2 of 2

Neutral modeled paths. Cut estimate adds 15 mm for terminations and another 20 mm on each phase extension. Existing motor, servo and battery leads may replace extensions; hand dress and measure first. Endpoint names indicate function, not exact solder-pad geometry.

Wire | AWG | Route / cut mm | Endpoint functions
Battery_stock_negative | 14 | 14 / 29 | B1 pack - -> XT60 battery half -
B1_positive | 14 | 121 / 137 | XT60 + -> Power splice +
B1_negative | 14 | 121 / 137 | XT60 - -> Power splice -
UBEC_input_0 | 22 | 104 / 119 | Power splice -> UBEC input
FC_input_0 | 26 | 35 / 51 | Power splice -> FC battery input
Capacitor_0 | 24 | 114 / 129 | Power splice -> C1
UBEC_input_1 | 22 | 113 / 128 | Power splice -> UBEC input
FC_input_1 | 26 | 34 / 50 | Power splice -> FC battery input
Capacitor_1 | 24 | 118 / 134 | Power splice -> C1
Receiver_0 | 26 | 25 / 41 | RP1 5V -> FC 5V
Receiver_1 | 26 | 25 / 41 | RP1 GND -> FC GND
Receiver_2 | 26 | 25 / 41 | RP1 TX -> FC RX2
Receiver_3 | 26 | 25 / 41 | RP1 RX -> FC TX2
Balance_0 | 26 | 19 / 35 | B1 balance tap -> J2 pin 1
Balance_1 | 26 | 19 / 35 | B1 balance tap -> J2 pin 2
Balance_2 | 26 | 19 / 35 | B1 balance tap -> J2 pin 3
Balance_3 | 26 | 19 / 35 | B1 balance tap -> J2 pin 4
Balance_4 | 26 | 19 / 35 | B1 balance tap -> J2 pin 5
Antenna_coax | 30 | 75 / 90 | RP1 UFL -> T antenna
Buzzer_wire_0 | 26 | 64 / 79 | Buzzer -> FC buzzer pad
Buzzer_wire_1 | 26 | 64 / 79 | Buzzer -> FC buzzer pad

42 routes are modeled and checked at neutral. Flexible travel, wire fatigue, wire-to-wire contact and every terminal/electronics pair are not continuously verified. Supplied antenna coax and pack balance leads are reference assemblies; do not fabricate or cut them from this table.

# Lift, mass & control feasibility

Case | Mass g | TWR at 12 V | TWR at 16 V
Nominal | 664.9 | 1.82 | 2.29
10% growth | 731.4 | 1.65 | 2.09
Target ceiling | 800 | 1.51 | 1.91

TWR = installed total static thrust / weight. The EMAX table covers original RS2205 2300KV motors with HQ5045BN two-blade props. An assumed 0.85 installed-thrust factor gives 1210 gf at 12 V and 1525 gf at 16 V, with a 24 A per-motor calculation ceiling where source data permit it. Neither factor nor limit is enforced firmware.

At nominal mass, simultaneous 20 degree pod tilt and 20 degree bank reduce vertical TWR to 1.61 at 12 V; at growth mass this falls to 1.46, before extra differential-command reserve. The growth case misses the preferred 1.8 vertical gate at low voltage. Fresh 16.8 V and hardware substitutes require new measurements.

## Two motors are enough only with the tilt mechanism

Command | Bicopter response
Climb / descend | Both motors change total thrust.
Roll / lateral translation | Differential motor thrust rolls the aircraft; bank redirects thrust.
Pitch / forward-back motion | Coordinated common pod tilt and body attitude redirect thrust.
Yaw / turn heading | Opposite pod tilt creates a yaw moment.

The local ideal model has sufficient control inputs, but pitch and yaw share servo travel: |common| + |differential| must stay within the absolute pod limit. TWR and controllability do not establish closed-loop stability.

## Servo and endurance limits

BMS-115WV+ catalog torque is 5.5 kgf cm at 6 V; the audit uses one-quarter of that only as an assumed working screen. A bounded 45 deg/s roll gives approximately 0.0735 N m total servo load versus a 0.1348 N m screen. At 180 deg/s the screen is exceeded. Real rotating inertia, RPM, heat, friction, linkage flex and loaded response remain unknown.

Estimated hover endurance is roughly 3-4 minutes with 80% of 4S1300 nominal energy and a 5 W avionics/servo allowance. This is a static estimate, not measured endurance or a landing timer. See the full independent audit for equations and sensitivity cases.

# Tail / balance and crosswind

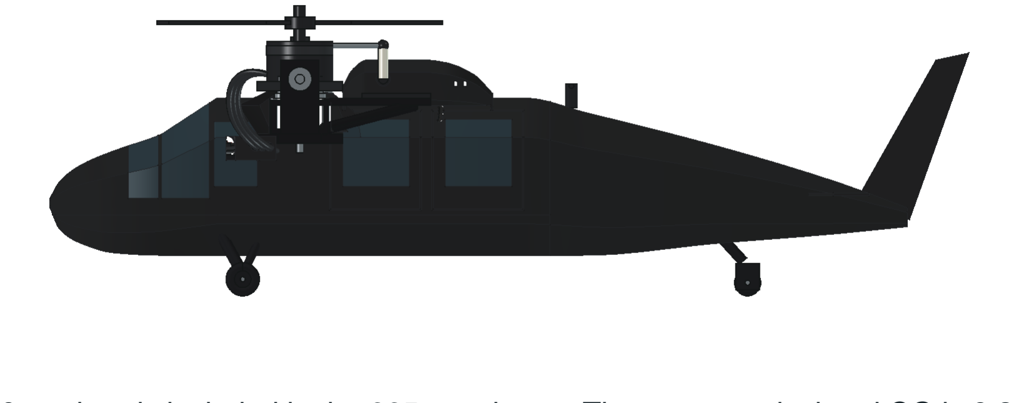
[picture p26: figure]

Tail prints total 30.86 g, already included in the 665 g estimate. The current calculated CG is 0.82 mm aft of the rotor pivot plane. Removing the tail parts without rebalancing would shift CG to 7.28 mm forward. Hardware and finish remain in shared allowances.

The long tail accounts for about 43% of the coarse pitch inertia estimate and 25% of yaw inertia. It therefore changes response even though it is only about 5% of total mass. The passive tail does not need a tail rotor and does not inherently prevent bicopter flight.

## Uniform side-flow sensitivity - no approved wind limit

Boom + fin summed side area is 71.38 cm^2, with a 179 mm area-weighted arm behind CG. Use N = 0.5 rho V^2 C integral[(CGx-x) dA], rho=1.225 kg/m^3. C=1.0-1.5 is an arbitrary sensitivity range, not measured or bounded aerodynamic data. Fin/boom overlap is double-counted; other aircraft surfaces and interference are excluded.

Side flow | Tail yaw moment, C=1.0-1.5 | Ideal yaw candidate used
3 m/s | 0.007-0.011 N m | 6-9%
5 m/s | 0.020-0.029 N m | 17-26%
8 m/s | 0.050-0.075 N m | 44-66%
10 m/s | 0.078-0.117 N m | 69-103%

The comparison uses about 0.114 N m ideal yaw authority near hover, after reserving common trim within an unqualified +/-10 degree absolute pod-angle candidate. It assumes coordinated thrust and no simultaneous maneuver demand. At the higher sensitivity cases the tail alone can consume most or all of that candidate authority.

Conclusion: mass and balance are plausible with the tail, but crosswind, pitch loads, vibration and tail-joint strength still need measurement. No wind speed in this table is a safe or approved operating limit. Full method and reproducible calculations: engineering/TAIL_ASSESSMENT.md.

# Printing & assembly sequence

## Start with fit coupons, then structural pieces

Centauri Carbon basis: 256 mm cube. All STL bounds fit, but supports, brim and orientation still require review. Print bearing, screw, shell seam and servo-retainer fit coupons before committing the complete aircraft.

Use actual material density when weighing the build. The current shell uses a 1 mm section-coordinate inset, not a guaranteed constant surface-normal wall. Layer orientation, infill, heat, creep and fatigue need qualification; no universal slicer recipe is asserted to be sufficient.

## 1. Resolve the hardware

Measure actual battery, motors, ESCs, servos and FC. Finalize trunnion shoulders/spacers/retainers, spline fit, motor screw engagement and tail splice. The existing envelopes are provisional.

## 2. Assemble the structure

Dry-fit keel, crossbeam, avionics deck and yokes. Install metal bearings and positively retained pins. Check endplay and independent pod rotation.

## 3. Fit actuators and electronics

Set verified mechanical neutral, fit horns/links and check range. Install FC isolation, receiver, dedicated servo BEC, ESCs, buzzer and capacitor with service access.

## 4. Route and inspect wiring

Follow net functions and measure actual cut lengths. Insulate the splice and provide strain relief. Check phase-wire bend radius throughout travel; neutral CAD fit does not establish flex life.

## 5. Close the body and tail

Resolve the x=-105 mm tail splice and tailwheel/gear retention before fitting shell and glazing. Check cooling, antenna placement and disconnect access.

## 6. Weigh and rebalance

Measure completed mass and three-axis CG with battery. Aim for CGx near zero using battery position; rerun the audit if geometry, hardware or weight changes.

Detailed task list: docs/BUILD_AND_TEST.md. This sequence organizes prototype assembly; unresolved joints prevent it from being a fully released manufacturing instruction.

# Verification & remaining gates

Completed computer checks | Scope / practical limit
167 valid physical CAD shapes | Topological validity; not stress, fatigue or actual hardware fit.
42 closed print meshes | 40 installed, 2 optional; bounding box within printer limits.
22 sampled rotor poses | Selected fixed-part pairs; minimum prop clearance 9.906 mm. No continuous or deflected motion proof.
42 neutral wire routes | 179,487 finite samples; no detected hits in completed scope. Not a flexible-harness or complete terminal-contact proof.
Mass, thrust and control screens | Source-based calculations and idealized models. No measured powertrain or tested flight tune.

## Required before flight qualification

- Props removed: continuity, polarity, separated regulated rails, firmware mixer/resources, motor/servo direction, endpoints, neutral and loss-of-signal behavior.
- Loaded electrical tests: simultaneous servo current, BEC sag, capacitor behavior and temperatures. Check the actual ESC protocol. Main pack current needs external measurement in this layout.
- Restrained propeller-on tests: exact installed thrust/current over actual pack voltage, motor/ESC temperature and body interference. Fresh-pack operation needs evidence.
- Mechanical tests: layer/joint strength, crank flex, tail splice proof, pin/axle retention, vibration, cyclic durability and real harness movement.
- Dynamic tests: loaded servo tracking including gyroscopic loads; tail crosswind and pitch moments; actual controller response and reserve under simultaneous commands.

The +/-10 degree pod/bank and <=45 deg/s body-rate values are investigation candidates, not implemented settings or approved limits. No PID tune, full-flight simulation, CFD or physical flight test has been completed.

Status: flight_release = false. Keep measured configuration, firmware hash/settings, scale/CG results, thrust curves, thermal logs and pass/fail evidence together. A valid solid and TWR above one do not alone establish reliable flight.

# References & project files

Primary specification references underpin the selected components. Exact battery SKU and generic hardware remain open. Reference pages are not a promise of current availability or endorsement. Full source snapshots and pinned Betaflight revisions are included in source/.
[MOTOR] EMAX RS2205 and test chart (https://emaxmodel.com/products/emax-rs2205-racespec-motor-cooling-series)

[ESC] EMAX motor / Lightning ESC combination (https://shop.emaxmodel.com/products/emax-rs2205-2300kv-2600kv-racespec-brushless-motor-with-3-4s-30a-blheli-lightning-esc-power-combo)

[SERVO] Blue Bird BMS-115WV+ catalog (https://www.blue-bird-model.com/products_detail/55.htm)

[FC] Matek F405-TE specifications and pinout (https://www.mateksys.com/?portfolio=f405-te)

### [BEC] Hobbywing UBEC 5A (https://www.hobbywing.com/en/products/ubec-5a93.html)

[RX] RadioMaster RP1 (https://www.radiomasterrc.com/products/rp1-expresslrs-2-4ghz-nano-receiver)

[BATTERY] Tattu battery family reference - not a selected SKU (https://www.genstattu.com/blog/tattu-fpv-battery-recommend)

### [PRINTER] Elegoo Centauri Carbon (https://www.elegoo.com/pages/elegoo-centauri-carbon)

[MIXER] Betaflight mixer documentation (https://betaflight.com/docs/wiki/guides/current/Mixer)

[AERO] NASA drag equation (https://www1.grc.nasa.gov/beginners-guide-to-aeronautics/drag-equation/)

[COEFFICIENT] NASA coefficient and flow-condition limitations (https://www1.grc.nasa.gov/beginners-guide-to-aeronautics/drag-coefficient/)

NASA references support the force equation and coefficient limitations; the numerical tail areas, coefficients and moments are this project's own explicitly limited calculations.

## Where to find the detail

Folder / file | Contents
cad/ | Native FreeCAD model and STEP assembly
stl/ | Installed printable pieces; optional guards in subfolder
engineering/ | Full audits, tail assessment, wire schedule, calculations and geometry-check evidence
docs/ | Purchase/print list, machine-readable parts and build/test plan
scripts/ | Geometry, analysis, audits, documentation and validation generators
REPRODUCE.md | Commands, dependencies and limits of reproducibility
NOTICE.md | Manufacturer references and third-party source attribution

### Repository: github.com/ar3116-sketch/kestrel-bicopter

Design intent: a small, matte-black, helicopter-inspired bicopter. This independent hobby project is not affiliated with the Black Hawk manufacturer or component vendors. No general open-source license has been selected.

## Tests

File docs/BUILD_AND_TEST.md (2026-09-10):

# Assembly and qualification plan

This document organizes the remaining prototype work. It is not a completed assembly release, approved flight procedure or tested firmware configuration.

## Resolve interfaces first

1. Select and measure the actual 4S1300 battery, motors, ESCs, BMS-115WV+ servos and flight controller. Check mass, mounting holes, shaft/horn dimensions, connector access and component height against CAD.
2. Finalize the bearing/trunnion shoulder, spacer and retaining arrangement. Verify servo horn engagement, ball-link travel, positive pod retention and motor-screw clearance from windings.
3. Detail the tail splice, shell closures, gear axle retention and all missing mounting fasteners. The current tail shell is split at x=-105 mm; the internal splice is explicitly provisional.
4. Recompute mass/CG and rotor clearance whenever interfaces change. No part currently owned means exact hardware fit remains an open requirement.

## Print and inspect

- Printer basis: Centauri Carbon, 256 x256 x256 mm. Each exported piece fits by its axis-aligned bounds; confirm bed orientation, brim and supports in the slicer.
- Print small bearing, screw, shell seam and servo-retainer fit coupons first. Do not commit the complete body before confirming tolerances.
- Use the actual filament density in the mass model. Current 1.24 g/cm^3 is a planning value. Shell geometry uses a 1 mm section-coordinate inset, which is not an exact constant normal wall thickness.
- Orient crossbeam, yokes, motor cradles, crank extensions and gear to resist their actual bending/joint loads. Layer direction, voids, heat, creep, inserts and fatigue have not been qualified. No fixed infill recipe is released as sufficient.
- Verify hot motor/ESC clearances and material behavior at measured temperatures. Do not assume PLA or any other named polymer is adequate solely from a catalog strength.
- Print one of every installed STL, dry-fit, weigh, then record the real mass. Guards are optional and are not included in baseline thrust-loss assumptions.

## Suggested assembly order

1. Assemble battery keel, crossbeam and avionics deck with isolators. Dry-fit the selected battery and confirm strap access.
2. Install yokes, metal bearings and retained trunnions. Check free pod rotation and endplay before fitting motors.
3. Install servos and verified OEM-compatible horns; set mechanical neutral and attach ball links. Check independent full travel without power wiring obstructing motion.
4. Mount FC, receiver, UBEC, ESCs, buzzer and capacitor. Keep electronics accessible for continuity and polarity checks.
5. Install the power and signal harness from the wiring schedule. Protect each splice and provide strain relief; verify flexible motor-phase loops through travel using the real insulation and bend radius.
6. Fit gear, completed tail joint, shell, glazing and cowls. Check cooling paths, radio antenna clearance and access to arming/disconnect controls.
7. Weigh the complete aircraft with battery and measure three-axis CG. Adjust the battery toward CGx=0; rerun calculations for the final state.

## Electrical and control checks - props removed

- Confirm no VBAT short, polarity, capacitor polarity and insulation before applying power through an appropriate current-limited commissioning setup.
- Verify regulated 6 V only feeds servos. FC 5 V feeds receiver/buzzer; grounds are common. Never join the 6 V and 5 V positive rails.
- Confirm the exact FC target and build include servo and bicopter support. The resource proposal is motors S1/PC9 and S2/PC8; servos S9/PB14 and S10/PA6. Mapping, output protocol, rates, neutral, sign and endpoints must be verified on the actual firmware.
- Verify the receiver is ELRS/CRSF-compatible and both receive/transmit wiring directions are correct. Check arm/disarm and loss-of-signal behavior.
- Confirm every stabilizing correction acts in the proper direction. Two motors alone are insufficient; both independent tilt servos must work correctly.
- Measure simultaneous loaded servo current and BEC voltage sag. The existing 4 A initial gate leaves nominal reserve below the 5 A continuous BEC rating; it does not replace transient/stall and thermal tests.
- Motor power bypasses the FC current sensor in this layout. Use external measurement if total pack current is required; do not trust an unconnected current-sensor channel.

## Restrained mechanical and propulsion qualification

- Use a guarded, restrained instrumented rig for propeller-on testing. Verify exact motor/prop rotation, thrust, current and temperature across the actual battery voltage range, including fully charged 16.8 V and sagged conditions.
- Measure installed thrust with body/cowls and verify reserve for bank, tilt and simultaneous commands. A source-table TWR is not an installed result.
- Proof-test primary structure and tail retention for the chosen load envelope, including landing and cyclic vibration. Screened beam stress does not qualify joints or layer adhesion.
- Test servo tracking under representative thrust, gyroscopic loads and harness resistance. Catalog stall torque and no-load speed do not establish usable continuous control bandwidth.
- Measure swept prop clearance and flexible wire movement at intermediate positions. Existing CAD sampling excludes deflection, vibration, wire fatigue and manufacturing error.
- Investigate tail side-force/yaw and tailplane pitch loads before approving a wind or speed envelope. Check resonance and vibration with the complete tail fitted.

## Flight qualification remains open

The +/-10 degree pod/bank and <=45 degree/s body-rate values in the audit are candidates for investigation, not implemented settings or safe limits. No PID tune, autonomous behavior or flight mode has been validated. A competent builder must establish controlled test conditions and progressively qualify stability and maneuvering after the above gates pass. The project currently has `flight_release=false` and no completed physical tests.

Record measured configuration, weights, CG, firmware hash/settings, battery state, thrust/current curves, temperatures, response logs and pass/fail evidence. Revise the CAD and calculations to match the tested hardware before calling the result flight-qualified.

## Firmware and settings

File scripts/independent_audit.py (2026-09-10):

"""Independent force, mass, control and gyroscopic screens. No CAD mutation.
Run: python3 independent_audit.py [path/to/revision]
Uses source-reference constants explicitly; nothing here qualifies hardware.
"""
from pathlib import Path
import json, math, sys

OUT = Path(__file__).resolve().parents[1] / 'engineering'
MODEL = Path(sys.argv[1]) if len(sys.argv) > 1 else Path(__file__).resolve().parents[1]
C = json.loads((MODEL/'engineering/calculations.json').read_text())
INV = json.loads((MODEL/'engineering/inventory.json').read_text())
MOV = json.loads((MODEL/'engineering/moving_objects.json').read_text())
g = 9.80665
mass = C['nominal_mass_g']
growth = C['mass_with_10percent_growth_g']
W = mass*g/1000
cg = C['cg_mm']
h = (35-cg[2])/1000
a = -cg[0]/1000
d = .117
Ixx,Iyy,Izz = C['inertia_kg_m2']
curves = {
 12:[(1,62),(3,162),(5,236),(7,311),(9.1,374),(11,439),(13,490),(15.3,548),(17.3,611),(20.7,712)],
 16:[(1,76),(3,183),(5,283),(7.1,352),(9.1,426),(11,497),(13,560),(15,628),(17,692),(19,754),(21,812),(23.3,878),(25.4,936),(27.3,997),(29.9,1024)]}

def interp(x, pts):
    for (x0,y0),(x1,y1) in zip(pts,pts[1:]):
        if x0<=x<=x1:return y0+(y1-y0)*(x-x0)/(x1-x0)
    raise ValueError('No extrapolation')

rows=[]
for mg in [mass,growth,800]:
    for V in [12,16]:
        for factor in [.85,.75,.65]:
            imax = min(24,curves[V][-1][0])
            f = interp(imax,curves[V])*factor*2
            amps = interp(mg/(2*factor), [(t,i) for i,t in curves[V]])
            rows.append(dict(mass_g=mg,voltage_V=V,installed_factor_assumed=factor,
                max_total_gf=f,hover_motor_A=amps,
                hover_total_with_5W_A=2*amps+5/V,
                vertical_TW=f/mg,pod20_TW=f/mg*math.cos(math.radians(20)),
                pod20_bank20_TW=f/mg*math.cos(math.radians(20))**2,
                pod20_bank20_with_10pct_diff_headroom_TW=f/mg*math.cos(math.radians(20))**2/1.1))

# Full 12-state, four-input small-disturbance hover model with zero X/Y CG error.
# States x,y,z,vx,vy,vz,phi,theta,psi,p,q,r; RH body X forward/Y left/Z up.
# Inputs collective N, differential N (L-R), common tilt rad, differential tilt rad (R-L)/2.
# xdd=g(theta+dc), ydd=-g phi; qdd coefficient through h. This is a local
# controllability calculation, NOT proof of a stable implemented controller.
n=12
A=[[0.]*n for _ in range(n)]
B=[[0.]*4 for _ in range(n)]
for r,c in [(0,3),(1,4),(2,5),(6,9),(7,10),(8,11)]: A[r][c]=1.
A[3][7]=g;A[4][6]=-g
B[5][0]=1000/mass;B[9][1]=d/Ixx;B[3][2]=g;B[10][2]=h*W/Iyy;B[11][3]=d*W/Izz
def mm(A,B):return [[sum(a*b for a,b in zip(row,col)) for col in zip(*B)] for row in A]
K=[row[:] for row in B];AB=B
for _ in range(n-1):
    AB=mm(A,AB)
    for row,new in zip(K,AB):row.extend(new)
def rank(M):
    M=[row[:] for row in M]; rr=0
    for col in range(len(M[0])):
        pivot=max(range(rr,len(M)), key=lambda j:abs(M[j][col]), default=rr)
        if rr==len(M) or abs(M[pivot][col])<1e-8:continue
        M[rr],M[pivot]=M[pivot],M[rr]
        s=M[rr][col];M[rr]=[v/s for v in M[rr]]
        for j in range(len(M)):
            if j!=rr:
                s=M[j][col];M[j]=[v-s*w for v,w in zip(M[j],M[rr])]
        rr+=1
        if rr==len(M):break
    return rr

trim=math.atan2(a,h)
authority=[]
for deg in [-20,-10,0,10,20]:
    angle=math.radians(deg)
    my=W*(h*math.tan(angle)-a)
    mz=d*W*math.tan(angle)
    authority.append(dict(angle_deg=deg,pitch_Nm_at_level_Fz_equals_W=my,
        pitch_accel_rad_s2=my/Iyy,yaw_Nm_zero_common_tilt=mz,yaw_accel_rad_s2=mz/Izz))

# Motion changes CG: rotate mass-envelope centroids about the actual transverse axes.
byname={o['name']:o for o in INV if o.get('installed',True)}
shifts=[]
for angle_deg in [-20,20]:
    angle=math.radians(angle_deg); sx=sz=0.
    for names in MOV.values():
        for name in names:
            o=byname.get(name)
            if not o:continue
            x,y,z=o['center_mm']; zr=z-35
            sx+=o['mass_g']*(x*math.cos(angle)+zr*math.sin(angle)-x)
            sz+=o['mass_g']*(-x*math.sin(angle)+zr*math.cos(angle)-zr)
    shifts.append(dict(common_tilt_deg=angle_deg,delta_CG_x_mm=sx/mass,delta_CG_z_mm=sz/mass,
        scope='listed moving shapes only, excluding linkage mass motion and wire flex'))

# Gyro torque under body roll: Omega_x cross H_z acts along pod hinge/servo axis Y.
# Prop mass is budgeted, not measured; uniform radial mass gives mR^2/3.
# The upper radial bound mR^2 is prop-only and excludes motor bell inertia.
R=.0635;mp=.003
Jrod=mp*R*R/3;Jradial=mp*R*R
gyro=[]
base_servo_load=C['servo'].get('base_quasistatic_load_Nm',C['servo']['screen_load_Nm'])
working=C['servo']['working_screen_Nm']
selected_servo=C['servo'].get('model','EMAX ES08MD II')
for rpm in [16000,20080,22830]:
    omega=rpm*2*math.pi/60
    for rate in [45,90,180]:
        p=math.radians(rate)
        t=Jrod*omega*p
        gyro.append(dict(rpm=rpm,roll_deg_s=rate,prop_only_uniform_radial_gyro_Nm=t,
            prop_only_radial_bound_gyro_Nm=Jradial*omega*p,
            base_plus_prop_estimate_Nm=base_servo_load+t,
            quarter_stall_margin_ratio=working/(base_servo_load+t),
            motor_bell_inertia='unknown, additional'))

mass_gates=[]
for factor in [.85,.75,.65]:
    maxmass=2*712*factor/1.8
    mass_gates.append(dict(installed_factor_assumed=factor,
        mass_g_for_1p8_vertical_at12V=maxmass,
        nominal_g_to_meet_1p8_after10pct_growth=maxmass/1.1,
        mass_g_for_1p6_at20deg_at12V=2*712*factor*math.cos(math.radians(20))/1.6))

ans=dict(audited_revision=MODEL.name,nominal_mass_g=mass,growth_mass_g=growth,
    source_table_transcription='Visually checked against source/motor_2.jpg; matches R3',
    cg_mm=cg,pivot_z_mm=35,pitch_arm_m=h,
    trim_deg_positive_is_thrust_toward_nose=math.degrees(trim),
    common_tilt_remaining_symmetric_deg=max(0,20-abs(math.degrees(trim))),
    linear_full_state_controllability_rank=rank(K),local_model_states=n,
    force_cases=rows,mass_gates=mass_gates,authority=authority,moving_cg_shifts=shifts,
    rotor_gyro=gyro,prop_inertia_uniform_radial_kg_m2=Jrod,
    prop_inertia_radial_bound_kg_m2=Jradial,
    note='Preliminary force/control screens; no measured hardware performance or validated flight dynamics.')
(OUT/'independent_audit_calculations.json').write_text(json.dumps(ans,indent=2))
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

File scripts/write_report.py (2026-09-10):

from pathlib import Path
import json,math,html
R=Path(__file__).resolve().parents[1]
C=json.loads((R/'engineering/calculations.json').read_text());I=json.loads((R/'engineering/inventory.json').read_text());W=json.loads((R/'engineering/wiring_routes.json').read_text())
clear=json.loads((R/'engineering/final_clearance_report.json').read_text()) if (R/'engineering/final_clearance_report.json').exists() else {}
m=C['nominal_mass_g'];mg=C['mass_with_10percent_growth_g'];cg=C['cg_mm'];n=sum(x['printed'] and x.get('installed',True) for x in I)
optional=[x for x in I if not x.get('installed',True)]
wire_sample=json.loads((R/'engineering/wire_sampling_check.json').read_text())
balance_status='The nominal calculation is inside the ±2 mm target; measure and trim the assembled aircraft.' if max(abs(cg[0]),abs(cg[1]))<=2 else 'The nominal calculation misses the ±2 mm target; redistribute hardware before flight.'
sources=[
('Original motor and manufacturer dimensions','https://emaxmodel.com/products/emax-rs2205-racespec-motor-cooling-series'),
('Exact 2300KV / HQ5045BN thrust table','https://cdn.shopify.com/s/files/1/0469/7358/3518/t/3/assets/RS2205-2.jpg?v=1598532544'),
('Motor / ESC kit','https://shop.emaxmodel.com/products/emax-rs2205-2300kv-2600kv-racespec-brushless-motor-with-3-4s-30a-blheli-lightning-esc-power-combo'),
('Selected Blue Bird BMS-115WV+ dimensions and torque','https://www.blue-bird-model.com/products_detail/55.htm'),
('Selected servo manufacturer','https://www.blue-bird-model.com/products_detail/55.htm'),
('Matek F405-TE hardware, output timers, supply','https://www.mateksys.com/?portfolio=f405-te'),
('Betaflight BI mixer','https://betaflight.com/docs/wiki/guides/current/Mixer'),
('Betaflight target pin assignment','https://github.com/betaflight/config/blob/d78c5a23515c8e05534a2989a2415f3fcd76fd19/configs/MTKS/MATEKF405TE_SD/config.h'),
('Betaflight servo mixer implementation','https://github.com/betaflight/betaflight/blob/9bf37771e1dad564d97245db479ddd7e3191c36a/src/main/flight/servos.c'),
('Hobbywing 5A UBEC specifications','https://www.hobbywing.com/en/products/ubec-5a93.html'),
('RadioMaster RP1 V2 receiver','https://www.radiomasterrc.com/products/rp1-expresslrs-2-4ghz-nano-receiver'),
('Tattu 4S1300 dimensional reference','https://www.genstattu.com/blog/tattu-fpv-battery-recommend'),
('Tenpower manufacturer cell list','https://www.tenpowercell.com.cn/products/cells'),
('User-linked Tenpower cell / conditional current ratings','https://www.18650batterystore.com/products/tenpower-50xg-21700-5000mah-90a-battery'),
('Centauri Carbon build envelope','https://www.elegoo.com/pages/elegoo-centauri-carbon')]
source_md='\n'.join(f'{i+1}. [{name}]({url})' for i,(name,url) in enumerate(sources))
case_md='\n'.join(f"| {x['mass_g']:.0f} | {x['voltage_V']} | {x['hover_total_A']:.1f} | {x['hover_power_W']:.0f} | {x['TW_vertical']:.2f} | {x['TW_at_20deg']:.2f} | {x['endurance_min']:.1f} |" for x in C['cases'])
parts_md='\n'.join(f"| {x['name']} | {x['mass_g']:.1f} | {' × '.join(f'{v:.1f}' for v in x['bbox_mm'])} | {x['solids']} |" for x in I if x['printed'] and x.get('installed',True))
wire_md='\n'.join(f"| {w['name']} | {w['net']} | {w['awg']} | {w['length_mm']:.0f} | {w['cut_length_mm']} | {w['from']} → {w['to']} |" for w in W)
body_issues=clear.get('body_intersections',[])+clear.get('component_pair_intersections',[])
wire_issues=clear.get('wire_structure_intersections',[]);moving_issues=clear.get('moving_structure_collisions',[])
prop_issues=[r for r in clear.get('tilt_checks',[]) if r['collisions']]
minimum=min((x['prop_to_fixed_min_mm'] for x in clear.get('tilt_checks',[])),default=0)
issues_md='\n'.join('- '+str(x) for x in body_issues+wire_issues+moving_issues) or 'No unresolved intersections above the listed thresholds remain. Matched cable passages are constructive checks; neutral wire fitting additionally uses dense approximate mesh sampling.'
report=f"""# Kestrel Mini R4 — engineering prototype

Designed in FreeCAD, 9 September 2026. Revision reflects the requested matte-black Black Hawk inspired silhouette: short rounded nose, sloping windshield, rectangular cabin windows, hollow roof fairings, low tail boom, swept fin and wheel gear. Original geometry inspired by the user's larger Samson model; no original CAD was overwritten. The two screenshot parts lists are references, not commands. No parts have been bought.

**Digital design and preliminary feasibility only. The aircraft has not been built, weighed, thrust-tested, structurally proof-tested, or flown. CAD cannot certify that it will fly.** This package is suitable for design review and fit prototypes; it is not a released flight kit.

## Main result

The calculated nominal build is **{m:.0f} g**, including a **77 g installation allowance**. The budget with 10% growth is **{mg:.0f} g**, leaving **{800-mg:.0f} g** below the user's 800 g ceiling. Printed material is **{C['printed_g']:.0f} g**, evaluated at full CAD solid volume and a conservative assumed 1.24 g/cm³. This is not a slicer prediction or measured print mass.

There are **{len(I)} modeled objects including two optional guards**, **{n} installed printable pieces**, and **{len(W)} individually modeled wire routes**. Rotor center spacing is 234 mm and prop diameter is 127 mm, giving 361 mm overall rotor span without guards. The swept fin gives approximately 386 mm overall length. Optional guards have 142.2 mm OD and 376.2 mm overall span. Body dimensions are not a uniform scale of the old design. The old package recorded 2699.9 g before contingency; this design is about {100*(1-m/2699.8677):.0f}% lighter on its own mass basis.

At nominal mass, the reference calculation with an assumed installation factor gives vertical thrust/weight of {C['cases'][0]['TW_vertical']:.2f} at 12 V and {C['cases'][1]['TW_vertical']:.2f} at 16 V, with installed thrust assumed to be 85% of the manufacturer stand result. Expected static hover duration is roughly **3–4 minutes** using 80% of nominal pack energy. Airflow obstruction, battery aging, wind, maneuvering and actual material mass can worsen this.

**The model predicts enough static lift at nominal weight. Maneuvering and stable controlled flight are not yet established.** The independent audit in `INDEPENDENT_FLIGHT_AUDIT.md` corrects the earlier servo-gyro omission and shows the sensitivity to weight and installed thrust. The 85% factor is an assumption, not a measured conservative bound. Keep the initial build near the nominal mass. At the 800 g ceiling, low-voltage tilt reserve is substantially weaker. The baseline omits the guards. Fitting both adds {C["optional_guards_g"]:.1f} g, taking nominal mass to {C["mass_with_optional_guards_g"]:.0f} g. No positive thrust gain is credited to them. Current screens below are analytical limits; hardware has not been configured to enforce them.

## What to open
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
